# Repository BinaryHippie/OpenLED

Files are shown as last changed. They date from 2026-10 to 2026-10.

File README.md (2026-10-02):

# OpenLED

OpenLED is a low-profile addressable RGB LED board intended for mounting on
OpenDrone frame arms. Each board carries four individually addressable
WS2812B-V6 LEDs and connects using solder pads for 5 V, ground and LED data.
An output set provides 5 V, ground and DOUT for optional daisy chaining.

The current design is a fixed 37 x 7 mm rigid PCB. It does not carry motor
current and does not include an onboard controller; LED data and 5 V power are
provided by the flight controller or another compatible source.

## Why

Arm-mounted LEDs can provide orientation, status indication and visual effects
without requiring a separate bulky lighting module.

OpenLED keeps the board simple: four addressable LEDs, direct solder-pad
connections and no additional controller. The design is intended to remain
lightweight, low profile, repairable and easy to integrate with OpenDrone
hardware.

The first revision is being developed as a reusable arm LED board. Prototype
PCBs are currently generated as 1x4 manufacturing panels and hand assembled.
Mechanical fit on the intended OpenFrame sizes must be verified physically
before frame compatibility is treated as final.

## Specifications

| | |
|---|---|
| Supply voltage | 5 V |
| LEDs | 4x WS2812B-V6 |
| LED type | Individually addressable RGB |
| Data interface | DIN / DOUT |
| Input connections | 5 V, GND, DIN solder pads |
| Output connections | 5 V, GND, DOUT solder pads |
| Bulk capacitance | 2x 10 uF |
| Local decoupling | 4x 100 nF, one per LED |
| PCB size | 37 x 7 mm |
| PCB thickness | 0.8 mm |
| Copper layers | 2 |
| Copper weight | 35 um |
| Board material | FR4 |

## Constraints

- The board is powered from a regulated 5 V source.
- Motor current must not be routed through the OpenLED PCB.
- The board has no onboard MCU or LED protocol controller.
- LED data enters at DIN and propagates through D1-D4 to DOUT.
- Each LED has a dedicated 100 nF local decoupling capacitor.
- Connections use solder pads rather than board-mounted connectors to minimise
  height and weight.
- The PCB is 37 x 7 mm with 1 mm corner radii.
- The design uses a front-layer 5 V plane and a back-layer GND plane.
- The board is intended for arm mounting and should remain compatible with
  heat-shrink or another lightweight strain-relief method.
- Mechanical compatibility with each intended OpenFrame size must be physically
  verified before release.
- Components should retain exact Manufacturer, MPN and LCSC fields where
  applicable.
- The project is authored in KiCad 10.
- Prototype panel generation is documented in `hardware/PANELIZATION.md`; the
  standalone `hardware/OpenLED.kicad_pcb` remains the board design source of
  truth.

## Design questions

- Confirm physical fit and mounting method on each intended OpenFrame size.
- Confirm the preferred wire routing and strain-relief method on an assembled
  arm.
- Validate LED visibility and spacing when installed under the intended
  protective covering.
- Confirm the production PCB finish and final assembly process after prototype
  testing.

## In the line

OpenLED is intended as an optional lighting accessory for OpenDrone builds.

It is designed to accept a 5 V supply and an addressable LED data signal from a
compatible flight controller, while retaining DOUT for optional chaining.

What pairs with what, and what is available:
[opendrone.be](https://opendrone.be).

## Contributing

See [CONTRIBUTING.md](CONTRIBUTING.md).

## License

Hardware licensed under
[CERN-OHL-S-2.0](https://ohwr.org/cern_ohl_s_v2.txt), see [LICENSE](LICENSE).

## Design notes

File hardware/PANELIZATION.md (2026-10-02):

# OpenLED 1x4 Manufacturing Panel

This document describes the reproducible manufacturing-panel workflow for
OpenLED.

The production panel contains four identical OpenLED boards, providing one
complete four-arm LED set for a drone.

## Panel configuration

- 1 column x 4 rows
- 4 identical OpenLED boards
- Individual board size: 37 mm x 7 mm
- PCB thickness: 0.8 mm
- Generated panel outline: approximately 53 mm x 53 mm
- 5 mm outer frame
- 3 mm spacing between boards and frame
- 5 mm breakaway tabs
- Routed slots with mouse-bite depanelization
- Mouse bites: 0.60 mm NPTH drill
- Mouse-bite pitch: 1.00 mm centre-to-centre
- Mouse-bite offset: -0.30 mm
- 6 mouse-bite holes per 5 mm tab
- 3 tooling holes, 2.0 mm diameter
- 3 fiducial locations on top and bottom copper
- No V-cuts

The tooling holes and fiducials are retained even when the prototype panels are
hand assembled. They keep the panel suitable for future automated assembly and
provide a consistent manufacturing-panel layout.

## Source of truth

The standalone board is the design source of truth:

    hardware/OpenLED.kicad_pcb

The generated panel is production output and must not be edited as the master
design.

Panel configuration is stored in:

    hardware/tools/panelize.json

KiKit post-processing is implemented in:

    hardware/tools/panel_post.py

The reproducible panel build is orchestrated by:

    hardware/tools/build_panel.py

Generated panel files are written below:

    hardware/production/panel/

The entire `hardware/production/` tree is ignored by Git because it contains
regenerable manufacturing output.

## Requirements

The panel workflow requires:

- KiCad
- Python
- KiKit

Run the build from an environment where Python and KiKit are available.

On Windows, the KiCad Command Prompt is the recommended environment unless
Python and KiKit have separately been added to the normal system PATH.

On Linux and macOS, a normal shell can be used when Python, KiCad and KiKit are
installed and available.

No absolute machine-specific paths are required.

## Generate the panel

From the repository root:

    python hardware/tools/build_panel.py

The script:

1. locates the OpenLED repository relative to its own path;
2. checks that KiKit is available;
3. creates `hardware/production/panel/` when required;
4. generates the 1x4 panel using `hardware/tools/panelize.json`;
5. applies `hardware/tools/panel_post.py`;
6. writes the panel-local footprint-library table;
7. writes panel-specific Fabrication Toolkit settings;
8. writes the fully resolved KiKit preset for inspection.

The normal generated board is:

    hardware/production/panel/OpenLED-panel-1x4.kicad_pcb

## KiKit source tolerance

The panel preset uses:

    tolerance: 15mm

This is a KiKit source-extraction tolerance, not a PCB manufacturing tolerance.

It enlarges the source extraction area so that panelization annotations and
other required board items extending outside the OpenLED Edge.Cuts are not
discarded.

The value is deliberately generous and has been verified with the current
OpenLED source board.

## Footprint libraries

The generated panel receives its own `fp-lib-table`.

Its project-local footprint library resolves through:

    ${KIPRJMOD}/../../lib.pretty

The shared OpenDrone library resolves through:

    ${KIPRJMOD}/../../KiCad-Library/footprint/OpenDrone.pretty

These are relative project paths. Do not replace them with absolute local
filesystem paths.

This allows a generated panel to be opened from a clone located anywhere on
Windows, Linux or macOS.

## Copper-zone handling

The standalone OpenLED PCB must have its copper zones filled and saved before
panel generation.

For the source board:

1. open `hardware/OpenLED.kicad_pcb`;
2. refill zones normally;
3. save the board;
4. run the normal source-board DRC.

The generated panel is different.

**DO NOT REFILL ZONES IN THE GENERATED PANEL.**

KiKit preserves the filled copper geometry from the individual source boards.
Refilling the generated panel can cause zones to extend into the sacrificial
tabs and panel structure.

Therefore:

- do not press `B` in the generated panel;
- disable `Refill all zones before performing DRC` when checking the panel;
- keep Fabrication Toolkit `AUTO FILL` disabled for the panel;
- regenerate the panel from the source board instead of manually modifying its
  copper zones.

`build_panel.py` automatically creates a panel-specific
`fabrication-toolkit-options.json` with:

    "AUTO FILL": false

The tracked source-board Fabrication Toolkit configuration remains separate and
may use normal zone refill.

## Panel post-processing

`hardware/tools/panel_post.py` marks KiKit tooling holes and fiducials as:

- excluded from BOM;
- excluded from position files;
- board-only objects.

KiKit handles the mouse-bite NPTH footprints separately.

This metadata is retained even though current prototypes are hand assembled so
the panel remains suitable for future automated assembly workflows.

## Manufacturing outputs

For the current prototype stage the boards are fabricated by JLCPCB and
assembled manually.

The PCB fabrication upload therefore uses the Gerber and drill archive from the
generated panel.

Fabrication Toolkit may also generate BOM and position files. These are retained
as useful generated outputs for verification and possible future automated
assembly, but they are not the authoritative component database.

The KiCad schematic remains authoritative for fitted components, manufacturer
part numbers and LCSC identifiers.

Do not manually maintain a second BOM as a source of truth.

## Verification

After any change affecting the board layout or panel configuration:

1. refill and save the standalone source PCB;
2. run source ERC and DRC;
3. regenerate the panel with `build_panel.py`;
4. visually inspect the generated panel;
5. run panel DRC with zone refill disabled;
6. inspect the generated Gerber and drill files;
7. verify BOM and position-file contents when generated.

A change to the panel preset requires the generated panel to be revalidated
before fabrication.

## Release status

The generated manufacturing files are prototype/in-progress outputs.

Do not create an OpenDrone `rev*` Git tag or GitHub release solely because a
prototype fabrication package has been generated.

The formal OpenDrone release process is performed after manufactured hardware
has been reviewed and the project reaches the appropriate project stage.

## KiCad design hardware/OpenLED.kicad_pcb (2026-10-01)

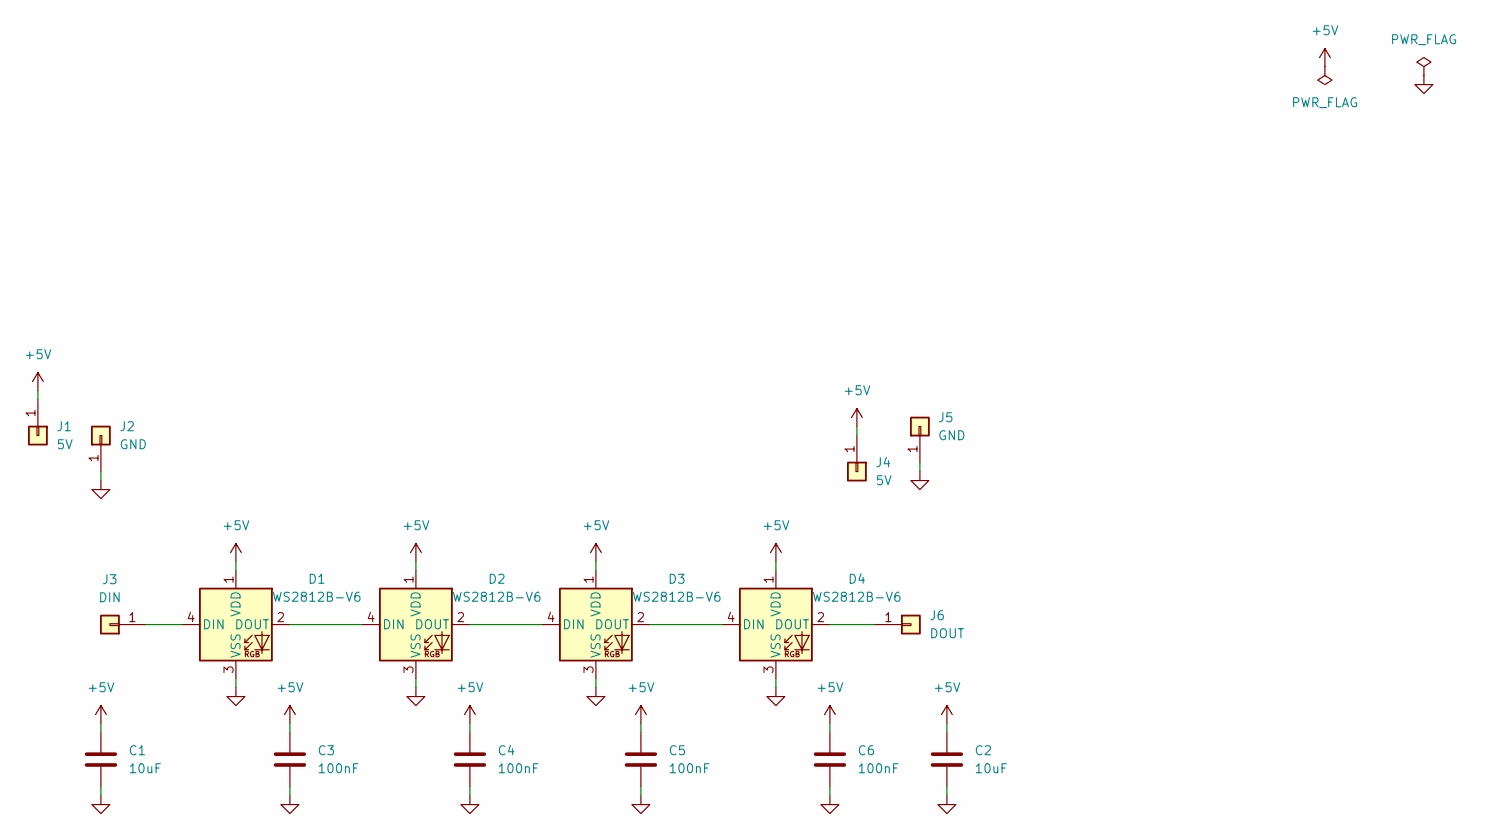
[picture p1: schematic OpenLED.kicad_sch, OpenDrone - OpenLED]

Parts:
C1, C2: 10uF; C_0603_1608Metric; MPN CL10A106KO8NQNC; LCSC C962136
C3, C4, C5, C6: 100nF; C_0402_1005Metric; MPN CL05B104KO5NNNC; LCSC C1525
D1, D2, D3, D4: WS2812B-V6; LED_WS2812B_PLCC4_5.0x5.0mm_P3.2mm; MPN WS2812B-V6; LCSC C52917433
J1, J4: 5V; SolderPad_2.2x1.6mm
J2, J5: GND; SolderPad_2.2x1.6mm
J3: DIN; SolderPad_2.2x1.6mm
J6: DOUT; SolderPad_2.2x1.6mm

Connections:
+5V: C1.1, C2.1, C3.1, C4.1, C5.1, C6.1, D1.1 (VDD), D2.1 (VDD), D3.1 (VDD), D4.1 (VDD), J1.1 (Pin_1_1), J4.1 (Pin_1_1)
GND: C1.2, C2.2, C3.2, C4.2, C5.2, C6.2, D1.3 (VSS), D2.3 (VSS), D3.3 (VSS), D4.3 (VSS), J2.1 (Pin_1_1), J5.1 (Pin_1_1)
unnamed: D1.4 (DIN), J3.1 (Pin_1_1)
unnamed: D1.2 (DOUT), D2.4 (DIN)
unnamed: D2.2 (DOUT), D3.4 (DIN)
unnamed: D3.2 (DOUT), D4.4 (DIN)
unnamed: D4.2 (DOUT), J6.1 (Pin_1_1)

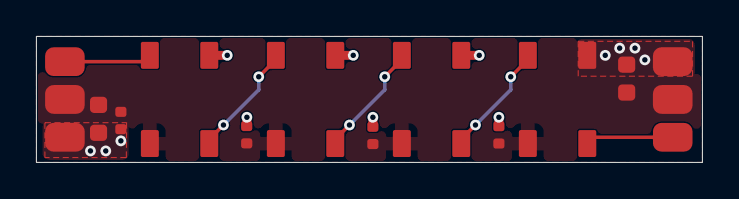
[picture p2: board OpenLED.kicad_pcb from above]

Board: 2 copper layers, 37.0 x 7.0 mm, 16 parts (0 on the bottom side), 7 nets.

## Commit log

2026-09-27 Migrate OpenLED design into OpenDrone hardware template
    [OpenLED.kicad_pcb, OpenLED.kicad_sch, board.kicad_pcb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]
2026-10-01 Prepare OpenLED rev0.1 hardware and panelization
    [OpenLED.kicad_pcb, OpenLED.kicad_sch]
